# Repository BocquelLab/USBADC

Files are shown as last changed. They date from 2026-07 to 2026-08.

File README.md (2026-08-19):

# USBADC
Le USBADC est un petit PCB qui implémente plusieurs fonctionnalités:
+ Lecture de la tension de sortie du power meter
+ Lecture de la température ambiante
+ Communication USB pour interfacer avec un ordinateur
+ Génération de 28 volts 1 ampère à partir de 12 volts 3 Ampères pour l'amplificateur RF
+ Génération de 5 volts pour le power meter
+ Contrôlle de la vitesse du ventilateur pour évacuer la chaleur
+ 6 sorties open-drain pour pouvoir controller des appareils nécessitant de la puissance (`PB1`, `PB3`, `PB4`, `PB5`, `PB6`, `PB7`)
+ 6 sorties digitales 3.3 volts pour du contrôlle ne nécessitant pas de puissance (`PA3`, `PA4`, `PA5`, `PA6`, `PA7`, `PA8`)
+ LED de statut du PCB, `D2` clignote lorsque le micro-contrôlleur n'a pas d'erreurs, et 4 autres LEDs indiquent si les générateurs de tensions fonctionnent (3.3V, 5V, 12V, 28V)

## Hardware
KiCad 10.0 a été utilisé pour la conception du schématique et du PCB.

### Composantes
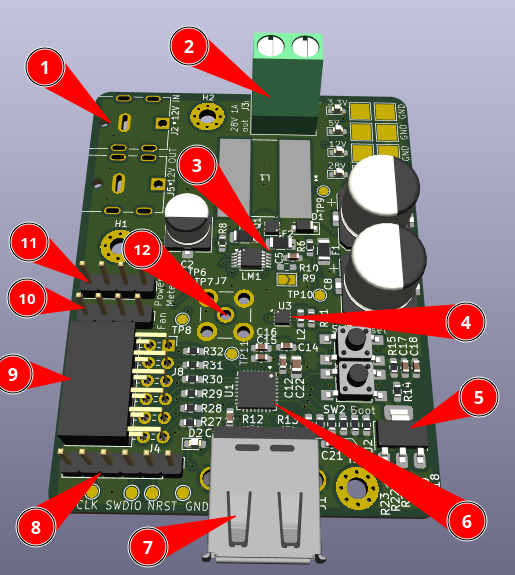
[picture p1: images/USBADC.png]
USBADC

1. Entré 12V 3A
2. Sortie 28V 1A
3. Boost 12V -> 28V
4. Buck 12V -> 5V
5. Régulateur 5V -> 3.3V
6. Microcontrôlleur STM32U073K8U6
7. Connecteur USB A femelle
8. Connecteur SWD (Single Wire Debug)
9. Sorties open-drain et low power
10. Sortie PWM pour fan
11. Sortie pour alimentation du powermeter et entrée de la température
12. Entrée pour lecture de la puissance RF

### Programmation
Pour envoyer un programme sur le micro-contrôlleur, il y a le port USB ainsi qu'un port SWD près du connecteur USB (header 6 pins).
Pour le flasher par USB, il faut utiliser le périphérique DFU (Download Firmware Upgrade) qu'expose le bootloader to STM32. Par contre, je ne sais pas pourquoi, je n'ai pas été capable de le faire fonctionner plus qu'une seule fois.

Pour le flasher par SWD, il faut un STlink. J'ai utilisé un [STlink-V3MINIE](https://www.st.com/en/development-tools/stlink-v3minie.html) auquel j'avais accès, il serait peut-être pertinent de s'en acheter un. J'ai aussi utilisé [stlink-tools](https://github.com/stlink-org/stlink) pour envoyer le programme. Il faut brancher:

| stlink | PCB |
|:---:|:-----:|
| VCC | VDD1  |
| CLK | SWCLK |
| GND | GND |
| TMS | SWDIO |
| RST | NRST  |

Le pinout du PCB est visible sur KiCad, l'ordre est VCC, SWCLK, GND, SWDIO, NRST, no-connect en partant de la pin extérieure.

### USB
La communication USB est faites avec un `STM32U073K8U6`, un micro-contrôlleur peu coûteux. C'est le moins cher qui a toutes les fonctionnalitées voulues, l'horloge pour le USB est générée à l'interne du chip.

### Génération 28V et 5V
Les bucks et boosts ont été générées avec l'outil [WEBENCH](https://webench.ti.com/power-designer/switching-regulator?powerSupply=0) de Texas Instrument pour être sûr que les circuits fonctionnent, jusqu'à maintenant, il n'y a eu aucuns problèmes.

### Sécurité
Pour la génération du 28V, il y a ~28 watts qui transitent dans cette partie du circuit. Il y a une fuse 4 ampères `F2` à l'entrée 12V du circuit et une fuse 1.5 ampères `F1` à la sortie 28V. De plus, il y a une diode schottky à la sortie 28V pour éviter d'envoyer des pics de tensions à l'amplificateur. Il y a aussi des condensateurs de capacitance équivalente 110µF pour lisser la tension entrante dans l'amplificateur.

Il y a des points de tests un peu partout sur le PCB pour être capable de débugger plus facilement si il arrive un problème.

### Boutons
Le PCB possède deux boutons, `BOOT0` et `Reset`.

`Reset` permet de redémarrer le microcontrôlleur, pratique pour débugger ou pour le redémarrer si il ne répond pas.

`BOOT0` permet de signaler au bootloader du microcontrôlleur que l'on désire flasher un programme pour qu'il expose la classe `DFU`. Il faut simplement tenir le bouton en appuyant sur `Reset`. Comme mentionné plus tôt, je ne comprends pas pourquoi je n'arrive pas à faire fonctionner cette option.

### Corrections à apporter sur une version future
Les connecteurs pour le ventilateur et le power meter overlap et ne peuvent donc pas être soudés directement sur le PCB.

Trouver pourquoi la programmation par DFU ne fonctionne pas et régler le problème.

Il m'est arrivé une fois que le board ne voulait pas démarrer, j'ai trouvé qu'il s'exposait comme périphérique DFU au démarage au lieu de CDC ACM et je n'étais pas capable de le faire booter plus loin que le bootloader. Je l'ai reflashé et ça a fonctionné, je n'ai pas revu ça depuis.

Mettre un connecteur USB mâle à la place d'un connecteur USB femelle car les connecteurs femelles sont réservés aux hôtes USB et les mâles aux périphériques.

Monitorer la tension du 28V avec le STM32 pour pouvoir voir son statut par USB au lieu de devoir regarder la LED. Sur la version actuelle, il est possible de mettre un diviseur de tension sur le pad 28V et rentrer ça dans la pin A3.

## Firmware
La grande majorité du code dans `firmware/` a été générée avec `STM32CubeMX`, un outil pour initialiser des projets pour des STM32, ils s'occupent d'initialiser toutes les périphériques, vérifier que la configuration de clocks choisie est correcte, etc.

Les paramètres pour CubeMX sont dans le fichier `firmware/USBADC.ioc`.

Le coeur de la logique a été implémentée dans `firmware/USBX/App/` en C.

### Compilation
Pour compiler le programme, il suffit d'écrire `make` si la toolchain de développement `arm` est installée. Je développais sur un ordinateur Linux et je roulais souvant 
```
make -j4; st-flash erase; st-flash write build/USBADC.bin 0x08000000
```
pour compiler et puis envoyer le programme sur le microcontrôlleur. Je ne suis pas certain que les `Makefile` sont supportés dans `STM32CubeIDE` (IDE de développement pour un STM32 installée sur l'ordinateur du laboratoire).

J'ai utilisé la "Arm GNU Toolchain 15.2.Rel1 (Build arm-15.86)) 15.2.1 20251203". Tout fonctionne avec celle là, il n'y a surement pas de soucis à prendre une autre version.

### Débuggage
Pour débugger, `STM32CubeIDE` et `stlink-tools` permettent d'ouvrir une session `gdb` et d'explorer la mémoire du microcontrolleur. Avec `stlink-tools`, je roulais dans un terminal `st-util` et dans l'autre `gdb build/USBADC.elf`, puis dans la session gdb `target remote localhost:4242`.

### Connection USB
Le périphérique USB crée expose une classe USB CDC ACM, (Character Device Class, Abstract Control Modem). Cette classe permet d'envoyer une série d'octet à l'appareil ainsi que d'en recevoir une. Lorsque branchée dans un ordinateur, le PCB devrait apparaître comme `/dev/ttyUSB*` sur Linux et `COM*` sur Windows. La LED devrait aussi clignotée si le microcontrôlleur est alimentée correctement et qu'il n'y a pas d'erreurs.

### Protocole de communication
La communication se produit par paquets entre le serveur (l'ordinateur) et le client (l'USBADC).
Un packet est une liste d'octets qui représente une commande ou une réponse. Le préfixe `0x` dénote de l'hexadécimale.

| Bytes | Name | Type | Description |
|---|---|---|---|
| `0-3` | Magic | `u8[4]` | `0xAA` `0x55` `0xAA` `0x55` |
| `4-5` | ID | `u16` | Request/response identifier. |
| `6` | Type | `u8` | Message type. |
| `7` | Data Length | `u8` | Bytes following this field. |
| `8..7+N` | Data | `u8[]` | Type-specific payload. |
| `8+N..11+N` | CRC | `u32` | Packet checksum using CRC32. |

Le champs `Magic` permet d'identifier le début d'un paquet. `0xAA55AA55` a été choisi car c'est une séquence qui a peu de chance d'arriver avec du bruit ou dans des données, aussi, en binaire, les bits de 0xAA et 0x55 alternent et ça permet de reconnaitre à l'oeil le début de la séquence.

Le champs `ID` permet à l'USBADC de spécifier à quel paquet il répond en spécifiant l'ID du message qu'il a reçu dans sa réponse. Cela permet de répondre aux paquets dans un ordre différent de celui dans lequel ils ont été reçues si besoin.

Le champs `Type` est le type du message (ping, read_adc, write_pin, reboot, ...) et permet de spécifier comment interpréter les données,

Le champs `Data Length` est la longeur du champs `Data` en octets

Le champs `Data` est les données associées au `Type` choisi.

Le champs `CRC` (Cyclical Redundancy Checksum) sert à vérifier l'intégrité des données reçues. Lors de la réception d'un paquet, on calcule le checksum de tous les octets précédents. Si le checksum est identique à celui reçue, on peut être confiant qu'il n'y a pas eu d'erreur de transmission.

Le protocole est ses fonctions de sérialisation/désérialisation sont spécifiées dans `firmware/USBX/App/protocol.h` et `firmware/USBX/App/protocol.c`.
Les structures qui représentent les données transmises ont l'attribut `__attribute__((packed))` pour éviter les champs de "padding". Cet attribute garanti qu'il n'y en aura pas.

Sur le message `REQUEST_PING`, le client répond avec le message `RESPONSE_PONG` avec les mêmes données. Cela permet de s'assurer que le client fonctionne correctement.

Sur le message `REQUEST_READ_ADC`, le client répond avec `RESPONSE_READ_ADC` la tension lue sur le channel correspondant.

Sur le mesasge `REQUEST_WRITE_PIN`, le client répond avec `RESPONSE_STATUS` et sort l'état demandée sur la pin demandée.

Sur le mesasge `REQUEST_REBOOT`, le client répond avec `RESPONSE_STATUS` et redémarre (la communication sera coupée).

Sur le message `REQUEST_VERSION`, le client répond avec la version du protocole qu'il utilise. Cela permet de s'assurer que le client et le serveur sont sur la même version et que toutes les fonctionnalitées sont fonctionelles et supportées des deux côtés.

Sur tous les messages, le client peut répondre avec `RESPONSE_STATUS` et spécifier la raison (`enum USBADC_PROTOCOL_RESPONS_STATUS_REASONS`).

### Fichiers (`firmware/USBX/App/`)
+ `app_usbx_device.c`: Point d'entrée `ThreadX` qui initialise les tâches et le périphérique USB et les files.
+ `ux_device_cdc_acm.c`: Définitions de toutes les tâches concurrentes qui roulent, dont l'écriture et la lecture sur le canal USB, la lecture de l'ADC et le contrôle de la vitesse du ventilateur.
+ `byte_vector.c`: Définition des fonctions pour manipuler une liste d'octets qui ne peut pas être agrandie.
+ `protocol.c`: Définition des fonctions pour sérialiser/désérialiser les packets envoyées/reçues

## Software
Python 3.11 a été utilisé.

Dans `software/USBADC.py`, il y a la classe `USBADC` qui permet de communiquer avec le périphérique. Il est nécessaire d'installer `pyserial` pour être capable de communiquer.

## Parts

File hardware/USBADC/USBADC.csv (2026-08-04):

Reference | Qty | Value | DNP | Exclude from BOM | Exclude from Board | Footprint | Datasheet
C1 | 1 | 10p |  |  |  | Capacitor_SMD:C_0603_1608Metric_Pad1.08x0.95mm_HandSolder
C2 | 1 | 100u |  |  |  | Capacitor_SMD:CP_Elec_6.3x5.8 | https://www.digikey.ca/en/products/detail/nichicon/UUD1C101MCL1GS/590003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
C3 | 1 | 1n |  |  |  | Capacitor_SMD:C_0603_1608Metric_Pad1.08x0.95mm_HandSolder
C4,C19,C20,C21 | 4 | 470p |  |  |  | Capacitor_SMD:C_0603_1608Metric_Pad1.08x0.95mm_HandSolder
C5 | 1 | 1.2u |  |  |  | Capacitor_SMD:C_0603_1608Metric_Pad1.08x0.95mm_HandSolder
C6,C8 | 2 | 220u |  |  |  | Capacitor_SMD:CP_Elec_10x10 | UUD1H221MNL1GS
C7,C12,C13,C17,C18 | 5 | 100n |  |  |  | Capacitor_SMD:C_0603_1608Metric_Pad1.08x0.95mm_HandSolder
C10,C11 | 2 | 10u |  |  |  | Capacitor_SMD:C_0805_2012Metric_Pad1.18x1.45mm_HandSolder | CL21A106KOQNNNE,https://www.digikey.ca/en/products/detail/samsung-electro-mechanics/CL21A106KOQNNNE/3886754
C14 | 1 | 4.7u |  |  |  | Capacitor_SMD:C_0603_1608Metric_Pad1.08x0.95mm_HandSolder
C15 | 1 | 10n |  |  |  | Capacitor_SMD:C_0603_1608Metric_Pad1.08x0.95mm_HandSolder
C16 | 1 | 1u |  |  |  | Capacitor_SMD:C_0603_1608Metric_Pad1.08x0.95mm_HandSolder
C22 | 1 | 10u |  |  |  | Capacitor_SMD:C_0603_1608Metric_Pad1.08x0.95mm_HandSolder
D1 | 1 | 550mV 2A |  |  |  | Diode_SMD:D_SOD-123F | https://www.digikey.ca/en/products/detail/onsemi/SS24FL/5305066
D2,D3,D4,D5,D6 | 5 | LED |  |  |  | LED_SMD:LED_0603_1608Metric_Pad1.05x0.95mm_HandSolder | https://www.digikey.ca/en/products/detail/liteon/LTST-C190KGKT/386815
D7 | 1 | 28V |  |  |  | Diode_SMD:D_SMA_Handsoldering | https://www.digikey.ca/en/products/detail/littelfuse-inc/SMAJ28CA/762293
F1,F2 | 2 | Fuse |  |  |  | Fuse:Fuse_1206_3216Metric_Pad1.42x1.75mm_HandSolder | https://www.digikey.ca/en/products/detail/bel-fuse-inc/0685T1500-01/4968265,https://www.digikey.ca/en/products/detail/bel-fuse-inc/0685T4000-01/4968270
J1 | 1 | USB_A |  |  |  | Connector_USB:USB_A_Molex_67643_Horizontal
J2,J5,J6 | 3 | JACK-C-PC-10A-RA_R |  |  |  | Library:GLOBTECK_JACK-C-PC-10A-RA_R_ | https://www.digikey.com/en/products/detail/globtek-inc/JACK-C-PC-10A-RA-R/8597889
J4 | 1 | Conn_01x06 |  |  |  | Connector_PinHeader_2.54mm:PinHeader_1x06_P2.54mm_Vertical
J7 | 1 | RFPC-SMA28-F |  |  |  | Library:GRADCONN_RFPC-SMA28-F
J8 | 1 | Conn_02x06_Odd_Even |  |  |  | Connector_PinSocket_2.54mm:PinSocket_2x06_P2.54mm_Horizontal
J9,J10 | 2 | Conn_01x04_Pin |  |  |  | Connector_PinHeader_2.54mm:PinHeader_1x04_P2.54mm_Vertical | https://www.digikey.ca/en/products/detail/molex/0470531000/2421261?s=N4IgTCBcDaIAwBYDscCsBmAjHHIC6AvkA
L1 | 1 | SDR1307-180ML |  |  |  | Library:IND_BOURNS_SDR1307 | SDR1307-180ML
L2 | 1 | 2.2u |  |  |  | Inductor_SMD:L_0603_1608Metric_Pad1.05x0.95mm_HandSolder | MLZ1608N2R2LT000
LM1 | 1 |  |  |  |  | Package_SO:TSSOP-10_3x3mm_P0.5mm | https://www.digikey.ca/en/products/detail/texas-instruments/LM3481MMX-NOPB/1840677
Q1 | 1 | CSD19538Q2 |  |  |  | Package_SON:Texas_DQK | https://www.ti.com/lit/ds/symlink/csd19538q2.pdf
Q2,Q3,Q4,Q5,Q6,Q7 | 6 | Q_NMOS_GSD |  |  |  | Package_TO_SOT_SMD:SOT-523 | https://www.digikey.ca/en/products/detail/diodes-incorporated/DMN62D0UT-7/5721509
R1 | 1 | 20m |  |  |  | Resistor_SMD:R_1206_3216Metric_Pad1.30x1.75mm_HandSolder | https://www.digikey.ca/en/products/detail/stackpole-electronics-inc/CSR1206FK20L0/1646092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
R2 | 1 | 44.2k |  |  |  | Resistor_SMD:R_0603_1608Metric_Pad0.98x0.95mm_HandSolder
R3 | 1 | 6.34 |  |  |  | Resistor_SMD:R_0603_1608Metric_Pad0.98x0.95mm_HandSolder
R4 | 1 | 73.2k |  |  |  | Resistor_SMD:R_0603_1608Metric_Pad0.98x0.95mm_HandSolder
R5 | 1 | 976 |  |  |  | Resistor_SMD:R_0603_1608Metric_Pad0.98x0.95mm_HandSolder
R6 | 1 | 21k |  |  |  | Resistor_SMD:R_0603_1608Metric_Pad0.98x0.95mm_HandSolder
R7 | 1 | 34k |  |  |  | Resistor_SMD:R_0603_1608Metric_Pad0.98x0.95mm_HandSolder
R8 | 1 | 100 |  |  |  | Resistor_SMD:R_0603_1608Metric_Pad0.98x0.95mm_HandSolder
R9 | 1 | 0 |  |  |  | Jumper:SolderJumper-2_P1.3mm_Open_TrianglePad1.0x1.5mm
R10 | 1 | 1 | DNP |  |  | Resistor_SMD:R_0603_1608Metric_Pad0.98x0.95mm_HandSolder
R11 | 1 | 100k |  |  |  | Resistor_SMD:R_0603_1608Metric_Pad0.98x0.95mm_HandSolder
R12 | 1 | 15k |  |  |  | Resistor_SMD:R_0603_1608Metric_Pad0.98x0.95mm_HandSolder
R13,R14,R15,R18,R19,R20,R21,R22,R23,R27,R28,R29,R30,R31,R32 | 15 | 10k |  |  |  | Resistor_SMD:R_0603_1608Metric_Pad0.98x0.95mm_HandSolder
R16,R17 | 2 | 62 |  |  |  | Resistor_SMD:R_0603_1608Metric_Pad0.98x0.95mm_HandSolder
R24 | 1 | 150 |  |  |  | Resistor_SMD:R_0603_1608Metric_Pad0.98x0.95mm_HandSolder
R25 | 1 | 510 |  |  |  | Resistor_SMD:R_0603_1608Metric_Pad0.98x0.95mm_HandSolder
R26 | 1 | 1300 |  |  |  | Resistor_SMD:R_0603_1608Metric_Pad0.98x0.95mm_HandSolder
SW2,SW3 | 2 | SW_Push |  |  |  | Button_Switch_SMD:SW_SPST_TL3305B | https://www.digikey.ca/en/products/detail/e-switch/TL3305BF100QG/25324184
TP5,TP6,TP7,TP8,TP9,TP10,TP11,TP12,TP13,TP14 | 10 | TestPoint |  |  |  | TestPoint:TestPoint_Pad_D1.5mm
TP17,TP18,TP20,TP21,TP23,TP24,TP25,TP29 | 8 | TestPoint |  |  |  | TestPoint:TestPoint_Pad_3.0x3.0mm
U1 | 1 | STM32U073K8Ux |  |  |  | Package_DFN_QFN:QFN-32-1EP_5x5mm_P0.5mm_EP3.45x3.45mm | https://www.st.com/resource/en/datasheet/stm32u073k8.pdf
U2 | 1 | AMS1117-3.3 |  |  |  | Package_TO_SOT_SMD:SOT-223-3_TabPin2 | http://www.advanced-monolithic.com/pdf/ds1117.pdf
U3 | 1 | TPS62173DSG |  |  |  | Package_SON:WSON-8-1EP_2x2mm_P0.5mm_EP0.9x1.6mm_ThermalVias | http://www.ti.com/lit/ds/symlink/tps62170.pdf

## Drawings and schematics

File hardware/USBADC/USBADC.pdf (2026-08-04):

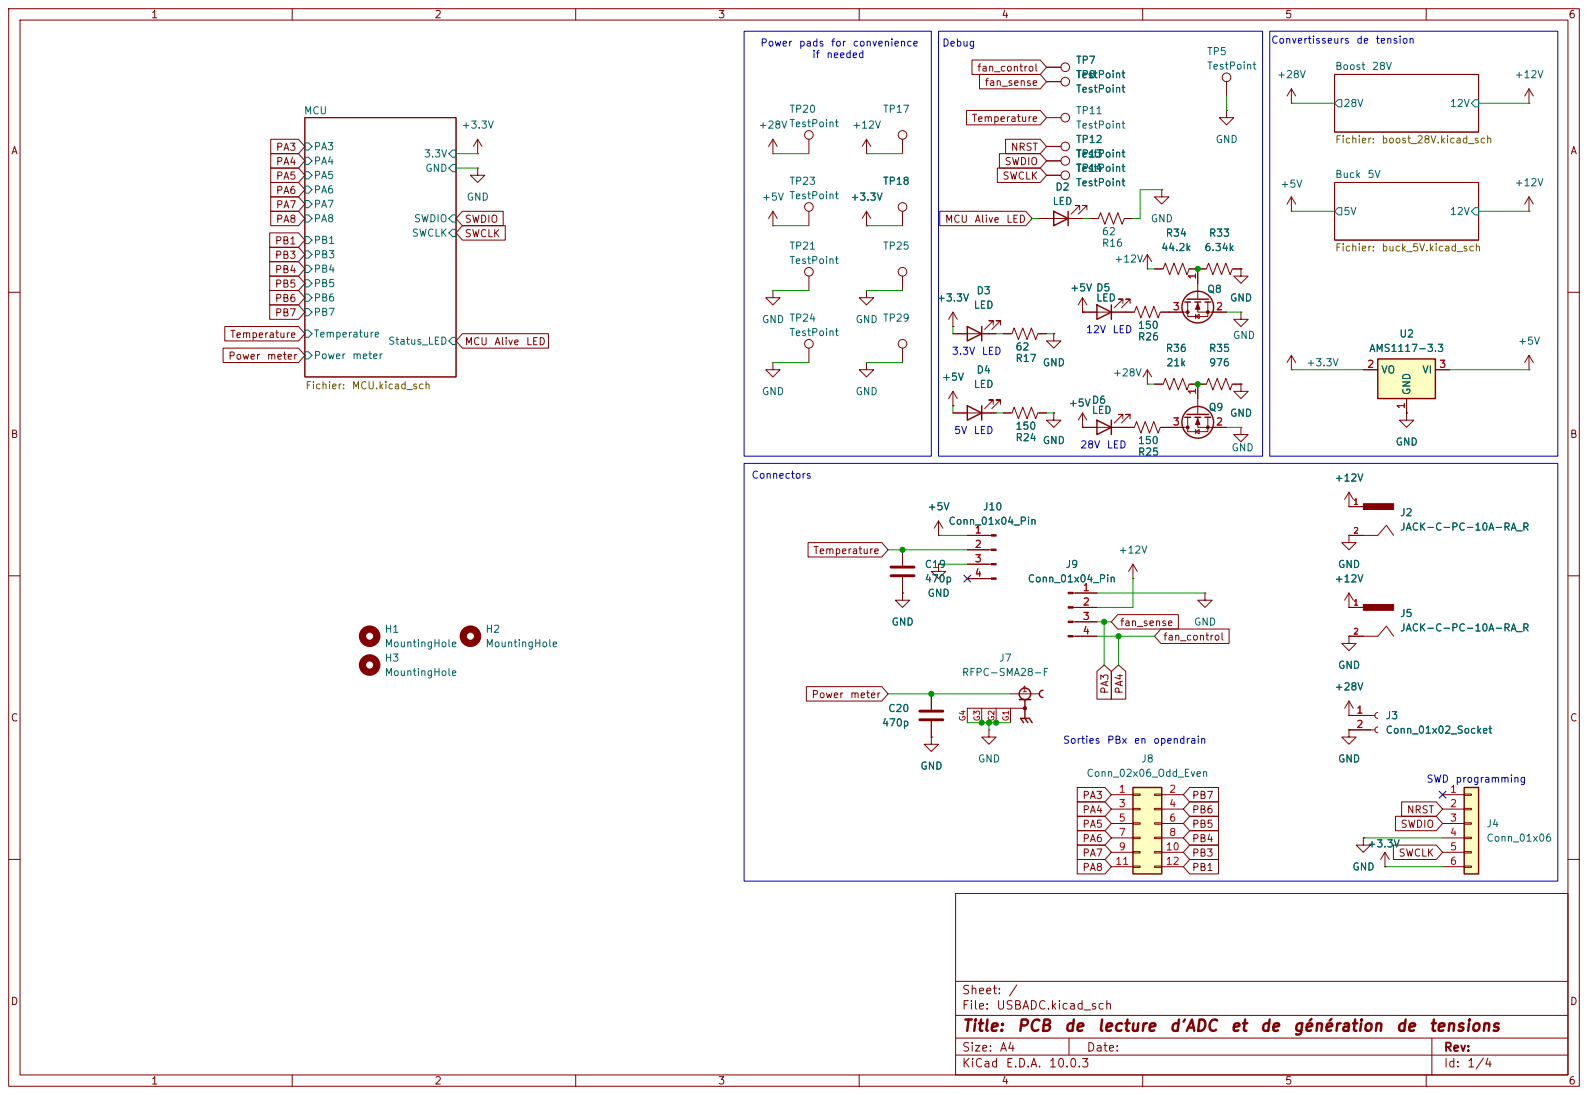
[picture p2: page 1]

Power pads for convenience

NRST SWCLK MCU Alive LED

SWD programming Sorties PBx en opendrain 3.3V LED

Sheet: /
File: USBADC.kicad_sch
Title: PCB de lecture d'ADC et de génération de tensions

Size: A4 | Rev:
KiCad E.D.A. 10.0.3 | Id: 1/4

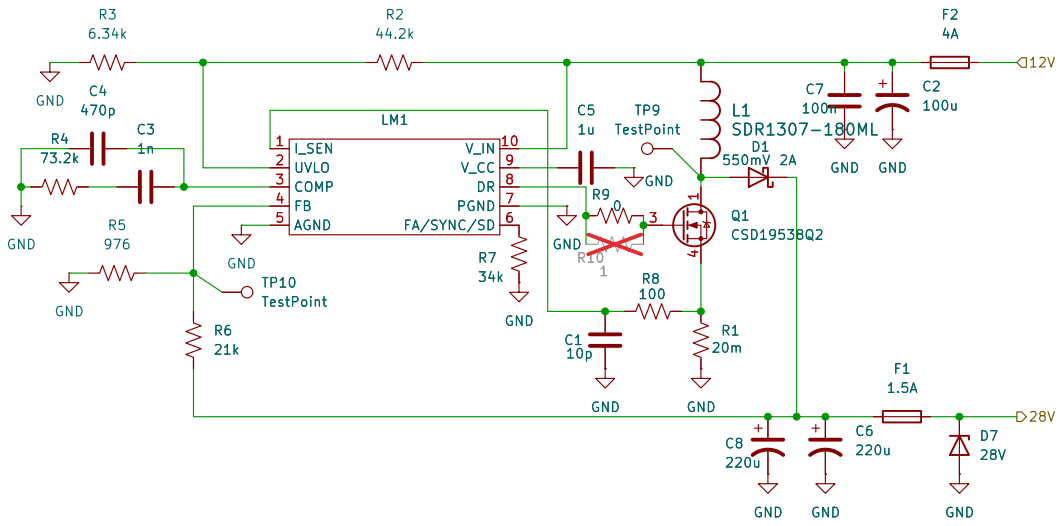
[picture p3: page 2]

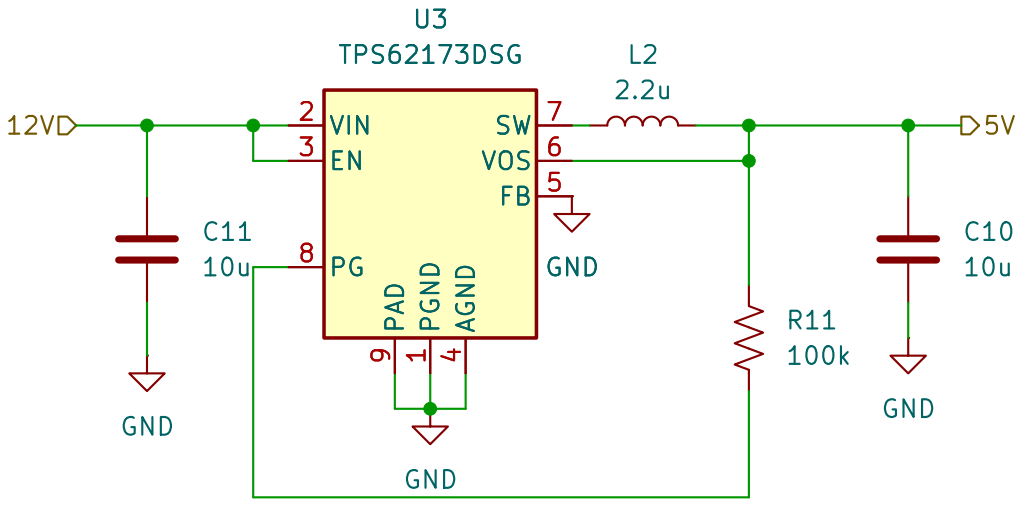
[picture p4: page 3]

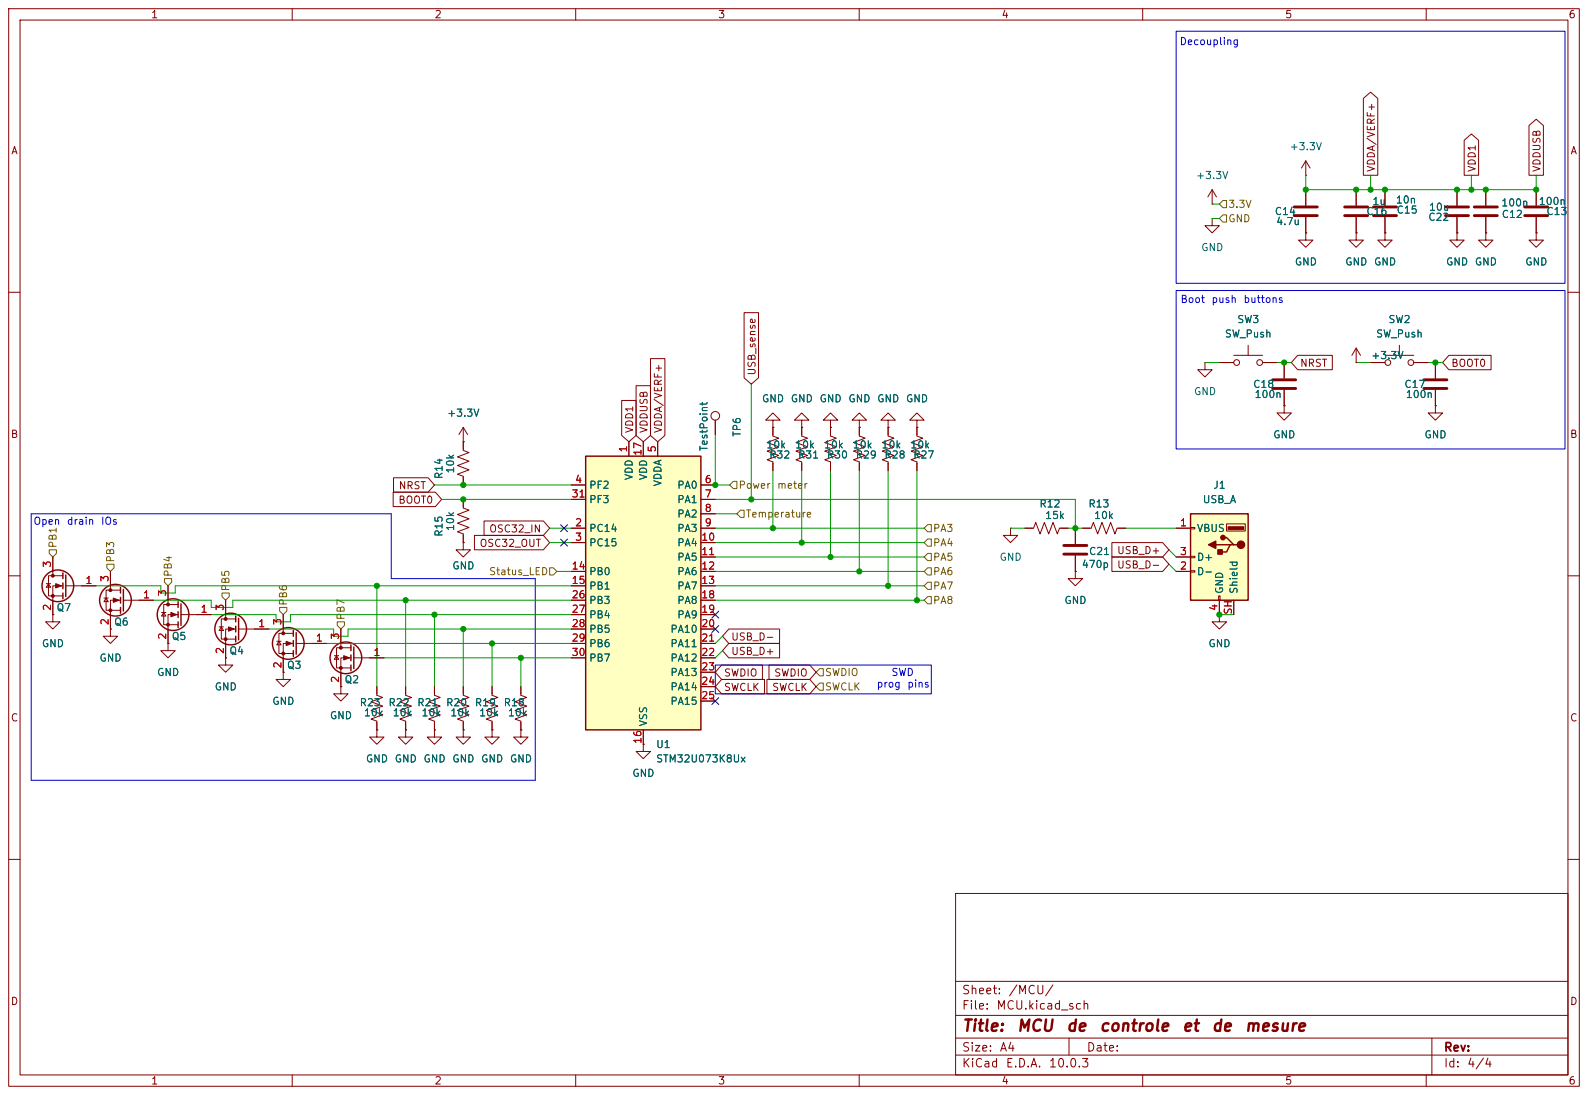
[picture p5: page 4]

SWCLK USB_D-USB_sense VDD1 VDDUSB VDDA/VERF+

1 PC14 2 PC15 3 PF2 4 VDDA 5 PA0 6 PA1 7 PA2 8 PA3 9 PA4 10 PA5 11 PA6 12 PA7 13 PB0 14 PB1 15 VSS 16 VDD 17 PA8 18 PA9 19 PA10 20 PA11 21 PA12 22 PA13 23 PA14 24 PA15 25 PB3 26 PB4 27 PB5 28 PB6 29 PB7 30 PF3 31 GND TP6 TestPoint C22

File: MCU.kicad_sch
Title: MCU de controle et de mesure

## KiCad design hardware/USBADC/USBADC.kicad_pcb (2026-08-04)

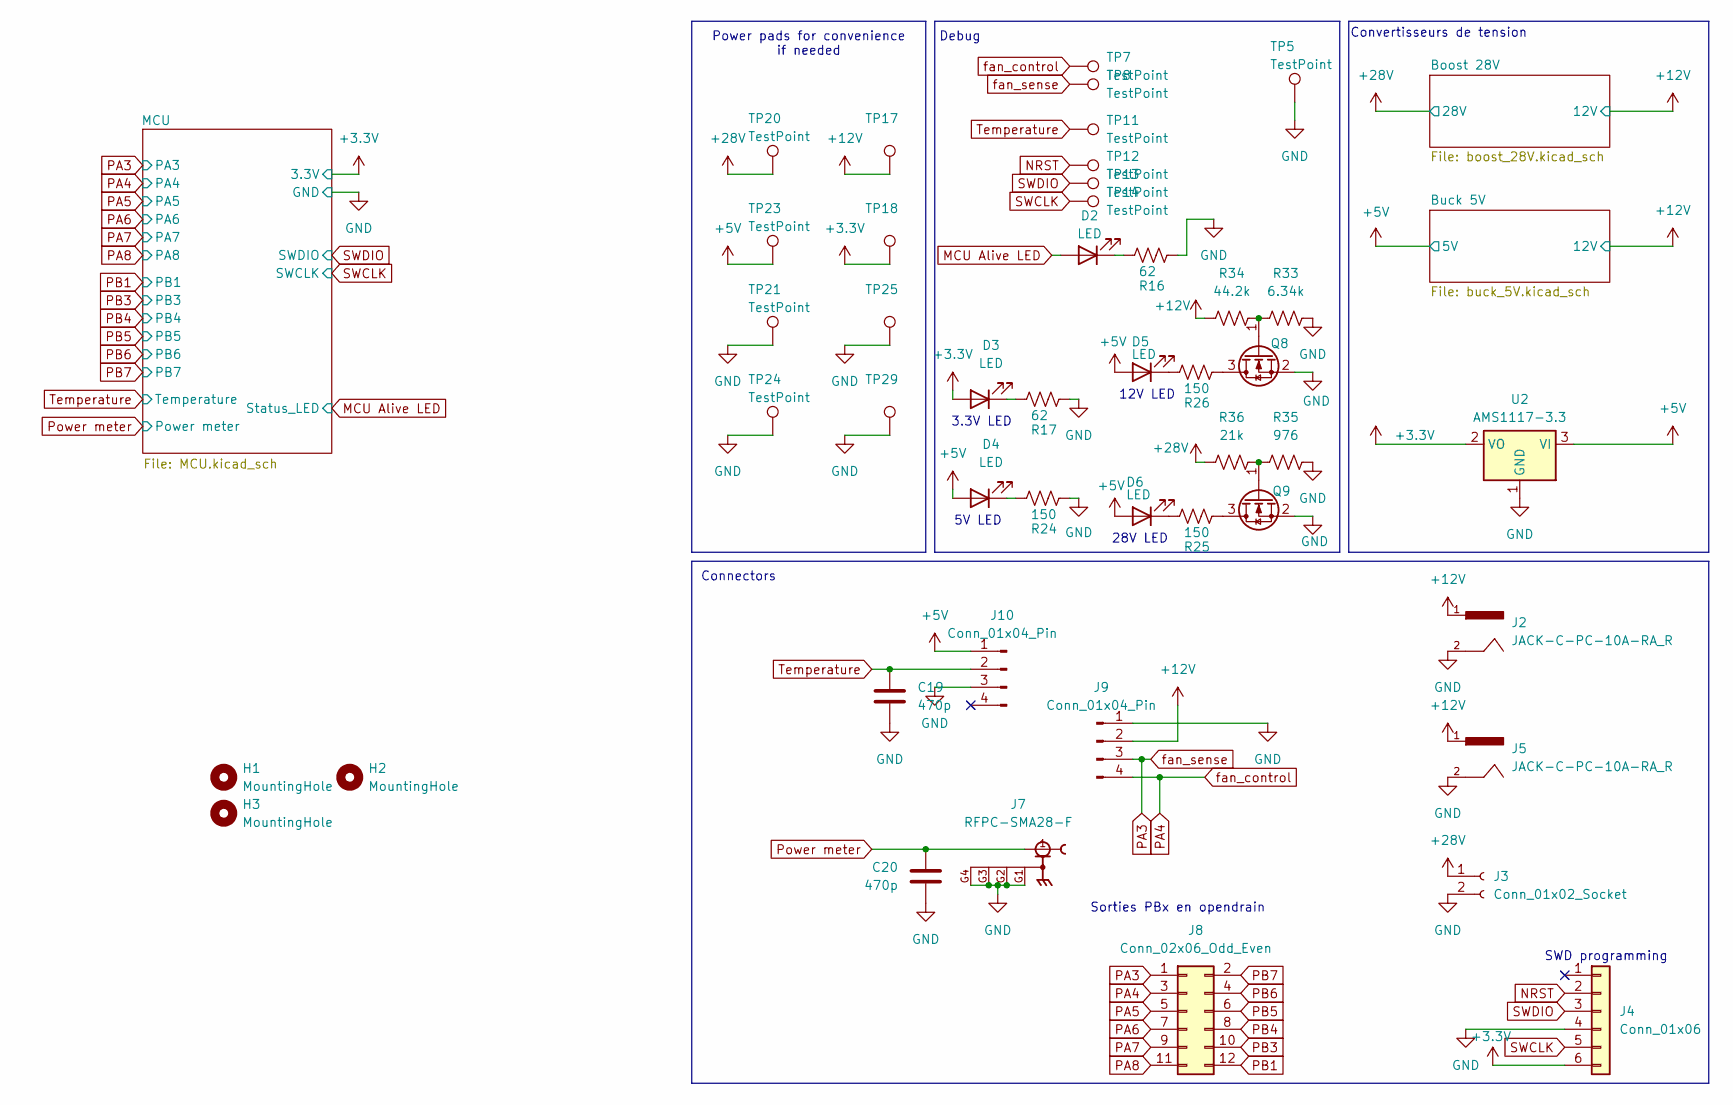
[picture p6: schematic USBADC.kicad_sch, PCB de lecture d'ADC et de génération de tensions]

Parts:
C19, C20: 470p; C_0603_1608Metric_Pad1.08x0.95mm_HandSolder
D2, D3, D4, D5, D6: LED; LED_0603_1608Metric_Pad1.05x0.95mm_HandSolder
H1, H2, H3: MountingHole; MountingHole_2.7mm_Pad_Via
J2, J5: JACK-C-PC-10A-RA_R; GLOBTECK_JACK-C-PC-10A-RA_R_; PARTREV A
J3: Conn_01x02_Socket; TerminalBlock_Phoenix_MKDS-1,5-2_1x02_P5.00mm_Horizontal
J4: Conn_01x06; PinHeader_1x06_P2.54mm_Vertical
J7: RFPC-SMA28-F; GRADCONN_RFPC-SMA28-F; PARTREV 1.0
J8: Conn_02x06_Odd_Even; PinSocket_2x06_P2.54mm_Horizontal
J9, J10: Conn_01x04_Pin; PinHeader_1x04_P2.54mm_Vertical
Q8, Q9: Q_NMOS_GSD; SOT-523
R16, R17: 62; R_0603_1608Metric_Pad0.98x0.95mm_HandSolder
R24, R25, R26: 150; R_0603_1608Metric_Pad0.98x0.95mm_HandSolder
R33: 6.34k; R_0603_1608Metric_Pad0.98x0.95mm_HandSolder
R34: 44.2k; R_0603_1608Metric_Pad0.98x0.95mm_HandSolder
R35: 976; R_0603_1608Metric_Pad0.98x0.95mm_HandSolder
R36: 21k; R_0603_1608Metric_Pad0.98x0.95mm_HandSolder
TP5, TP7, TP8, TP11, TP12, TP13, TP14: TestPoint; TestPoint_Pad_D1.5mm
TP17, TP18, TP20, TP21, TP23, TP24, TP25, TP29: TestPoint; TestPoint_Pad_3.0x3.0mm
U2: AMS1117-3.3; SOT-223-3_TabPin2

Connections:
+5V: D4.2 (A), D5.2 (A), D6.2 (A), J10.1, TP23.1 (1_1), U2.3 (VI); also elsewhere on the board
+12V: J2.1, J5.1, J9.2, R34.1, TP17.1 (1_1); also elsewhere on the board
+28V: J3.1, R36.1, TP20.1 (1_1); also elsewhere on the board
GND: C19.1, C20.1, J2.2, J3.2, J4.4, J5.2, J7.G1, J7.G2, J7.G3, J7.G4, J9.1, J10.3, Q8.2 (S), Q9.2 (S), R16.1, R17.1, R24.1, R33.1, R35.1, TP5.1 (1_1), TP21.1 (1_1), TP24.1 (1_1), TP25.1 (1_1), TP29.1 (1_1), U2.1 (GND); also elsewhere on the board
MCU Alive LED: D2.2 (A); also elsewhere on the board
NRST: J4.2, TP12.1 (1_1); also elsewhere on the board
unnamed: D2.1 (K), R16.2
unnamed: D3.1 (K), R17.2
unnamed: D4.1 (K), R24.2
unnamed: D5.1 (K), R26.2
unnamed: D6.1 (K), R25.2
unnamed: Q8.3 (D), R26.1
unnamed: Q8.1 (G), R33.2, R34.2
unnamed: Q9.3 (D), R25.1
unnamed: Q9.1 (G), R35.2, R36.2
PA3: J8.1, J9.3, TP8.1 (1_1); also elsewhere on the board
PA4: J8.3, J9.4, TP7.1 (1_1); also elsewhere on the board
PA5: J8.5; also elsewhere on the board
PA6: J8.7; also elsewhere on the board
PA7: J8.9; also elsewhere on the board
PA8: J8.11; also elsewhere on the board
PB1: J8.12; also elsewhere on the board
PB3: J8.10; also elsewhere on the board
PB4: J8.8; also elsewhere on the board
PB5: J8.6; also elsewhere on the board
PB6: J8.4; also elsewhere on the board
PB7: J8.2; also elsewhere on the board
Power meter: C20.2, J7.1; also elsewhere on the board
SWCLK: J4.5, TP14.1 (1_1); also elsewhere on the board
SWDIO: J4.3, TP13.1 (1_1); also elsewhere on the board
Temperature: C19.2, J10.2, TP11.1 (1_1); also elsewhere on the board
VDD1: D3.2 (A), J4.6, TP18.1 (1_1), U2.2 (VO); also elsewhere on the board

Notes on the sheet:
SWD programming
Convertisseurs de tension
28V LED
Connectors
Power pads for convenience if needed
12V LED
Debug
Sorties PBx en opendrain
3.3V LED
5V LED

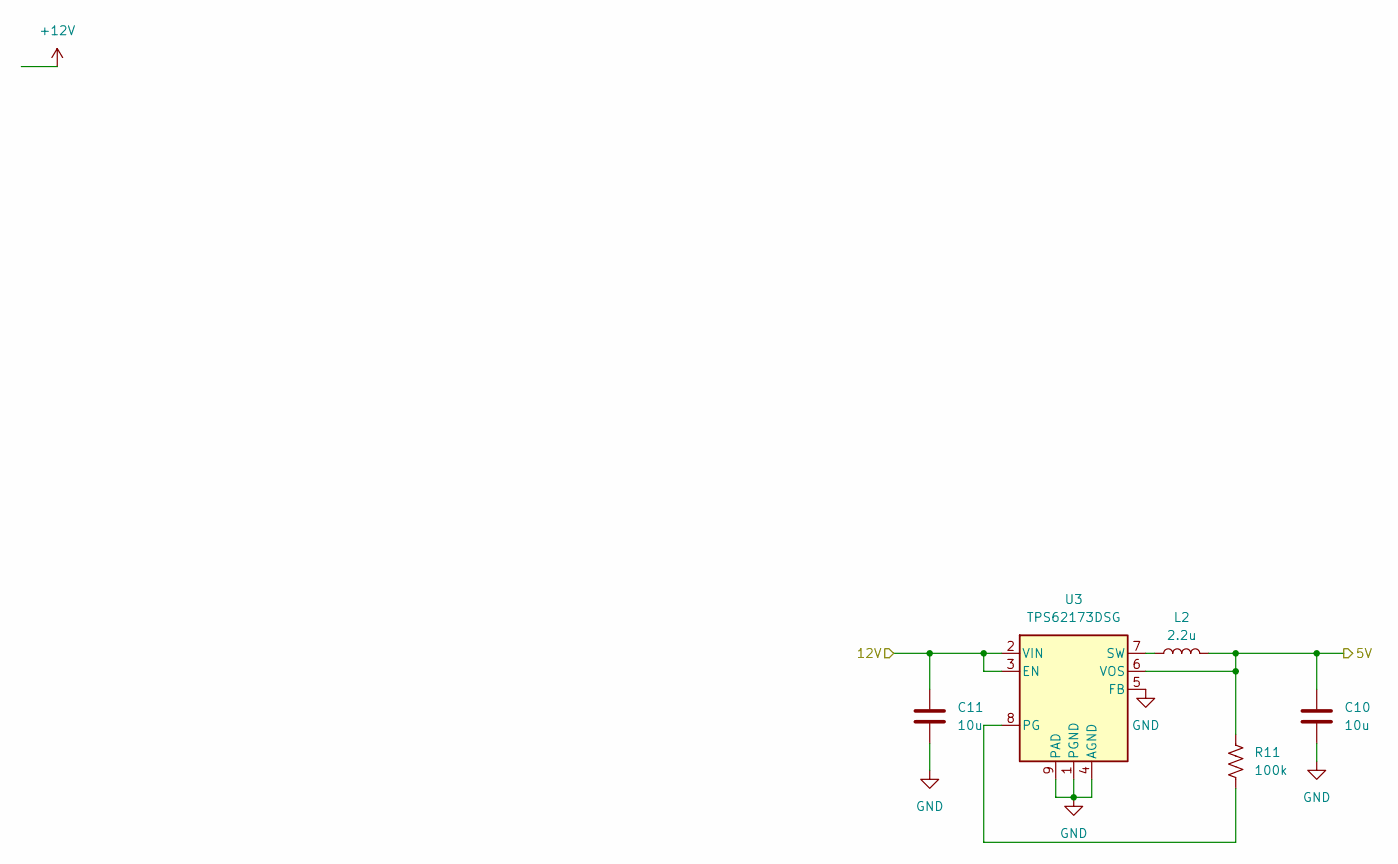
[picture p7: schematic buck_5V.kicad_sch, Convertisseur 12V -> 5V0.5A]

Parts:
C10, C11: 10u; C_0805_2012Metric_Pad1.18x1.45mm_HandSolder
L2: 2.2u; L_0603_1608Metric_Pad1.05x0.95mm_HandSolder
R11: 100k; R_0603_1608Metric_Pad0.98x0.95mm_HandSolder
U3: TPS62173DSG; WSON-8-1EP_2x2mm_P0.5mm_EP0.9x1.6mm_ThermalVias

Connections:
+5V: C10.1, L2.2, R11.1, U3.6 (VOS); also elsewhere on the board
+12V: C11.1, U3.2 (VIN), U3.3 (EN); also elsewhere on the board
GND: C10.2, C11.2, U3.1 (PGND), U3.4 (AGND), U3.5 (FB), U3.9 (PAD); also elsewhere on the board
unnamed: R11.2, U3.8 (PG)
unnamed: L2.1, U3.7 (SW)

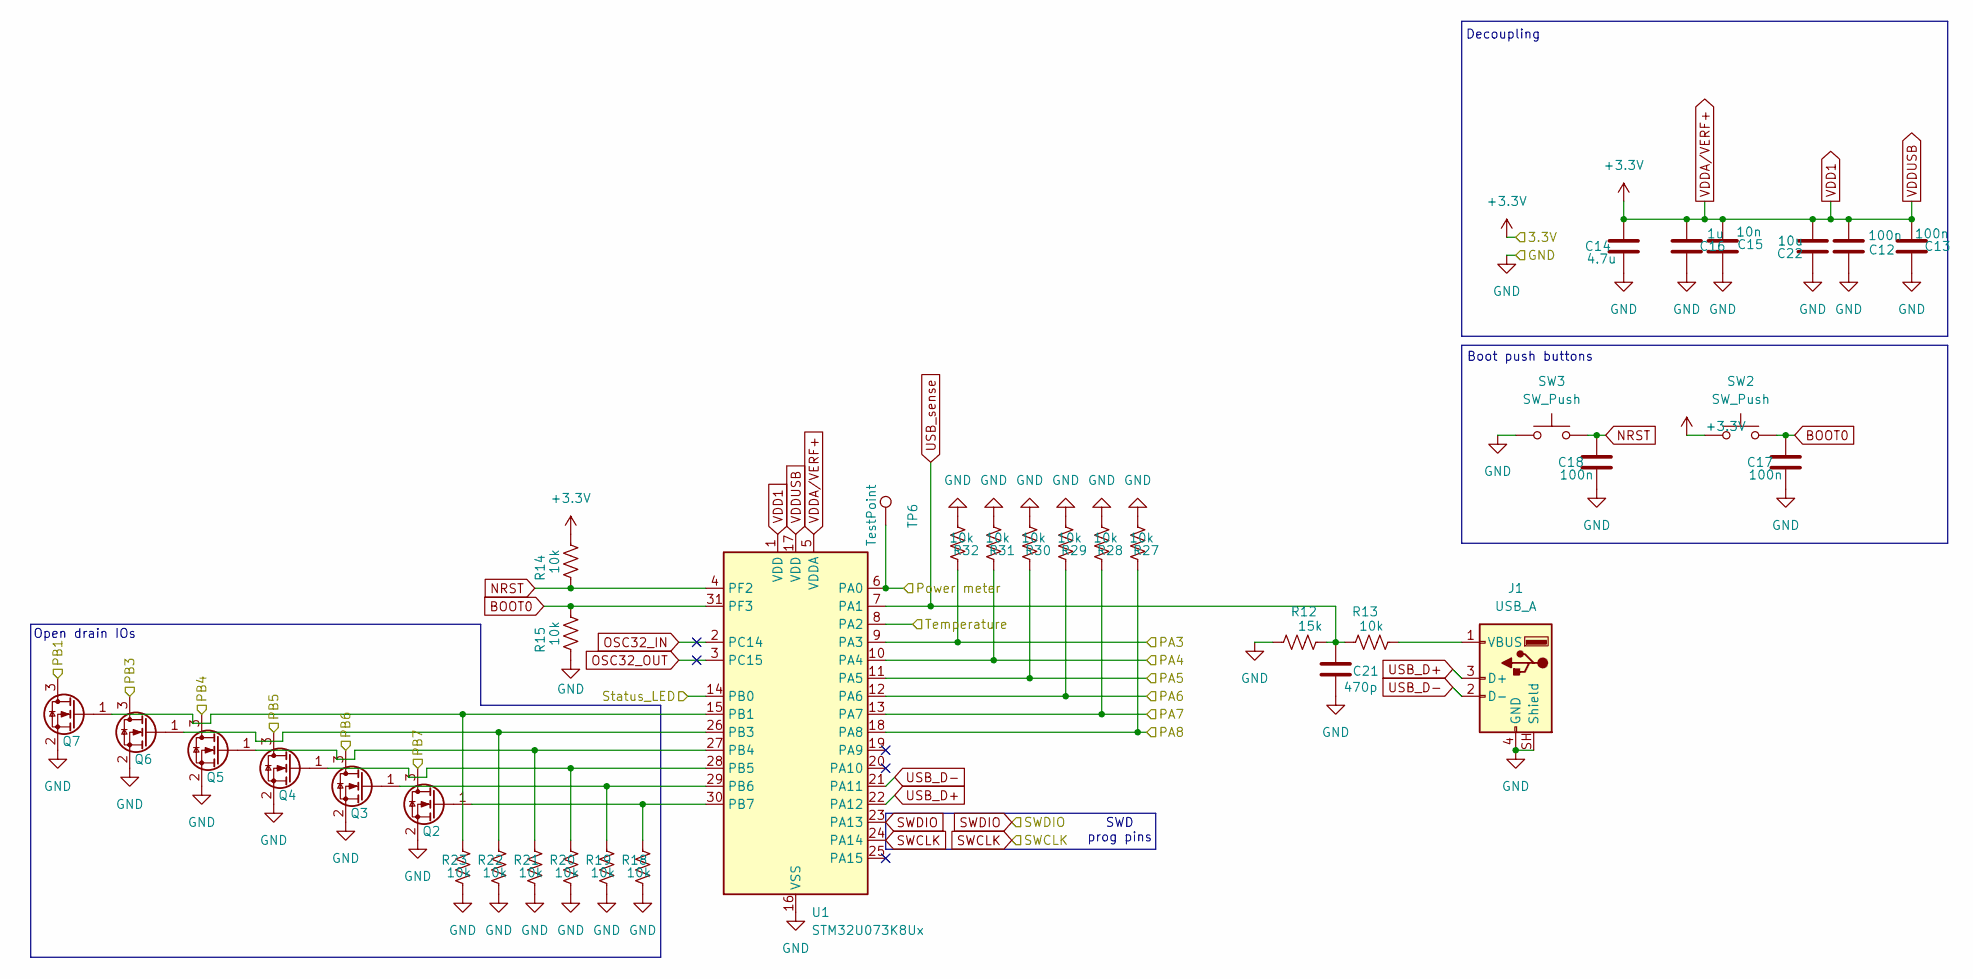
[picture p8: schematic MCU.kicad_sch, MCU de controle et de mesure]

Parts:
C12, C13, C17, C18: 100n; C_0603_1608Metric_Pad1.08x0.95mm_HandSolder
C14: 4.7u; C_0603_1608Metric_Pad1.08x0.95mm_HandSolder
C15: 10n; C_0603_1608Metric_Pad1.08x0.95mm_HandSolder
C16: 1u; C_0603_1608Metric_Pad1.08x0.95mm_HandSolder
C21: 470p; C_0603_1608Metric_Pad1.08x0.95mm_HandSolder
C22: 10u; C_0805_2012Metric_Pad1.18x1.45mm_HandSolder
J1: USB_A; USB_A_Molex_67643_Horizontal
Q2, Q3, Q4, Q5, Q6, Q7: Q_NMOS_GSD; SOT-523
R12: 15k; R_0603_1608Metric_Pad0.98x0.95mm_HandSolder
R13, R14, R15, R18, R19, R20, R21, R22, R23, R27, R28, R29, R30, R31, R32: 10k; R_0603_1608Metric_Pad0.98x0.95mm_HandSolder
SW2, SW3: SW_Push; SW_SPST_TL3305B
TP6: TestPoint; TestPoint_Pad_D1.5mm
U1: STM32U073K8Ux; QFN-32-1EP_5x5mm_P0.5mm_EP3.45x3.45mm

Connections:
BOOT0: C17.1, R15.2, SW2.2, U1.31 (PF3)
GND: C12.1, C13.1, C14.2, C15.1, C16.1, C17.2, C18.2, C21.1, C22.1, J1.4 (GND), J1.SH (Shield), Q2.2 (S), Q3.2 (S), Q4.2 (S), Q5.2 (S), Q6.2 (S), Q7.2 (S), R12.1, R15.1, R18.1, R19.1, R20.1, R21.1, R22.1, R23.1, R27.1, R28.1, R29.1, R30.1, R31.1, R32.1, SW3.1, U1.16 (VSS), U1.32 (VSS), U1.33 (VSS); also elsewhere on the board
MCU Alive LED: U1.14 (PB0); also elsewhere on the board
NRST: C18.1, R14.1, SW3.2, U1.4 (PF2); also elsewhere on the board
unnamed: J1.1 (VBUS), R13.2
unnamed: Q2.1 (G), R18.2, U1.30 (PB7)
unnamed: Q3.1 (G), R19.2, U1.29 (PB6)
unnamed: Q4.1 (G), R20.2, U1.28 (PB5)
unnamed: Q5.1 (G), R21.2, U1.27 (PB4)
unnamed: Q6.1 (G), R22.2, U1.26 (PB3)
unnamed: Q7.1 (G), R23.2, U1.15 (PB1)
OSC32_IN: U1.2 (PC14)
OSC32_OUT: U1.3 (PC15)
PA3: R32.2, U1.9 (PA3); also elsewhere on the board
PA4: R31.2, U1.10 (PA4); also elsewhere on the board
PA5: R30.2, U1.11 (PA5); also elsewhere on the board
PA6: R29.2, U1.12 (PA6); also elsewhere on the board
PA7: R28.2, U1.13 (PA7); also elsewhere on the board
PA8: R27.2, U1.18 (PA8); also elsewhere on the board
PB1: Q7.3 (D); also elsewhere on the board
PB3: Q6.3 (D); also elsewhere on the board
PB4: Q5.3 (D); also elsewhere on the board
PB5: Q4.3 (D); also elsewhere on the board
PB6: Q3.3 (D); also elsewhere on the board
PB7: Q2.3 (D); also elsewhere on the board
Power meter: TP6.1 (1_1), U1.6 (PA0); also elsewhere on the board
SWCLK: U1.24 (PA14); also elsewhere on the board
SWDIO: U1.23 (PA13); also elsewhere on the board
Temperature: U1.8 (PA2); also elsewhere on the board
USB_D+: J1.3 (D+), U1.22 (PA12)
USB_D-: J1.2 (D-), U1.21 (PA11)
USB_sense: C21.2, R12.2, R13.1, U1.7 (PA1)
VDD1: C12.2, C13.2, C14.1, C15.2, C16.2, C22.2, R14.2, SW2.1, U1.1 (VDD), U1.5 (VDDA), U1.17 (VDD); also elsewhere on the board

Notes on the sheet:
SWD prog pins
Open drain IOs
Boot push buttons
Decoupling

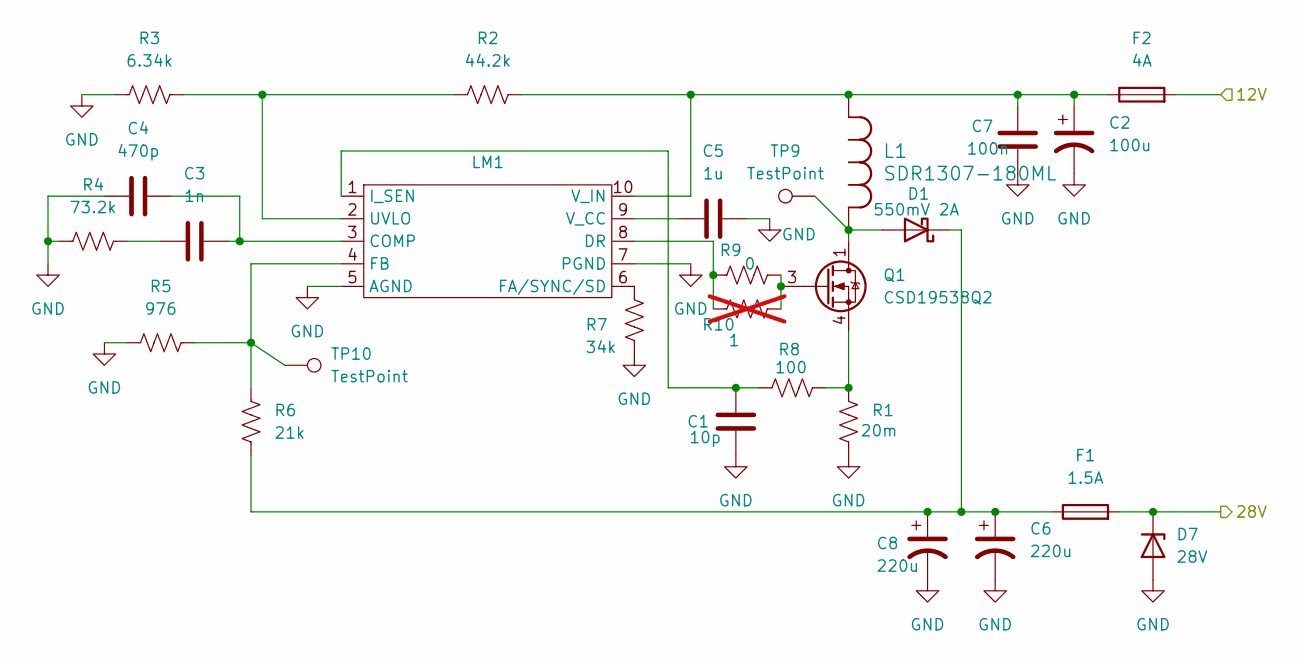
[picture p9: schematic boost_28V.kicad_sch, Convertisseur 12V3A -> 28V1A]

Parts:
C1: 10p; C_0603_1608Metric_Pad1.08x0.95mm_HandSolder
C2: 100u; CP_Elec_6.3x5.8
C3: 1n; C_0603_1608Metric_Pad1.08x0.95mm_HandSolder
C4: 470p; C_0603_1608Metric_Pad1.08x0.95mm_HandSolder
C5: 1u; C_0603_1608Metric_Pad1.08x0.95mm_HandSolder
C6, C8: 220u; CP_Elec_10x10
C7: 100n; C_0603_1608Metric_Pad1.08x0.95mm_HandSolder
D1: 550mV 2A; D_SOD-123F
D7: 28V; D_SMA_Handsoldering
F1: 1.5A; Fuse_1206_3216Metric_Pad1.42x1.75mm_HandSolder
F2: 4A; Fuse_1206_3216Metric_Pad1.42x1.75mm_HandSolder
L1: SDR1307-180ML; IND_BOURNS_SDR1307
LM1: TSSOP-10_3x3mm_P0.5mm
Q1: CSD19538Q2; Texas_DQK
R1: 20m; R_1206_3216Metric_Pad1.30x1.75mm_HandSolder
R2: 44.2k; R_0603_1608Metric_Pad0.98x0.95mm_HandSolder
R3: 6.34k; R_0603_1608Metric_Pad0.98x0.95mm_HandSolder
R4: 73.2k; R_0603_1608Metric_Pad0.98x0.95mm_HandSolder
R5: 976; R_0603_1608Metric_Pad0.98x0.95mm_HandSolder
R6: 21k; R_0603_1608Metric_Pad0.98x0.95mm_HandSolder
R7: 34k; R_0603_1608Metric_Pad0.98x0.95mm_HandSolder
R8: 100; R_0603_1608Metric_Pad0.98x0.95mm_HandSolder
R9: 0; SolderJumper-2_P1.3mm_Open_TrianglePad1.0x1.5mm
R10: 1; R_0603_1608Metric_Pad0.98x0.95mm_HandSolder; not fitted
TP9, TP10: TestPoint; TestPoint_Pad_D1.5mm

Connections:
+12V: F2.2; also elsewhere on the board
+28V: D7.1 (K), F1.2; also elsewhere on the board
GND: C1.2, C2.2, C4.1, C5.2, C6.2, C7.1, C8.2, D7.2 (A), LM1.5 (AGND), LM1.7 (PGND), R1.2, R3.2, R4.2, R5.2, R7.2; also elsewhere on the board
unnamed: C3.1, R4.1
unnamed: D1.2 (A), L1.1, Q1.1 (D), Q1.2 (D), Q1.5 (D), Q1.6 (D), Q1.8 (D), TP9.1 (1_1)
unnamed: C6.1, C8.1, D1.1 (K), F1.1, R6.2
unnamed: C3.2, C4.2, LM1.3 (COMP)
unnamed: LM1.8 (DR), R9.1, R10.1
unnamed: LM1.6 (FA/SYNC/SD), R7.1
unnamed: LM1.4 (FB), R5.1, R6.1, TP10.1 (1_1)
unnamed: C1.1, LM1.1 (I_SEN), R8.1
unnamed: LM1.2 (UVLO), R2.1, R3.1
unnamed: C5.1, LM1.9 (V_CC)
unnamed: C2.1, C7.2, F2.1, L1.2, LM1.10 (V_IN), R2.2
unnamed: Q1.3 (G), R9.2, R10.2
unnamed: Q1.4 (S), Q1.7 (S), R1.1, R8.2

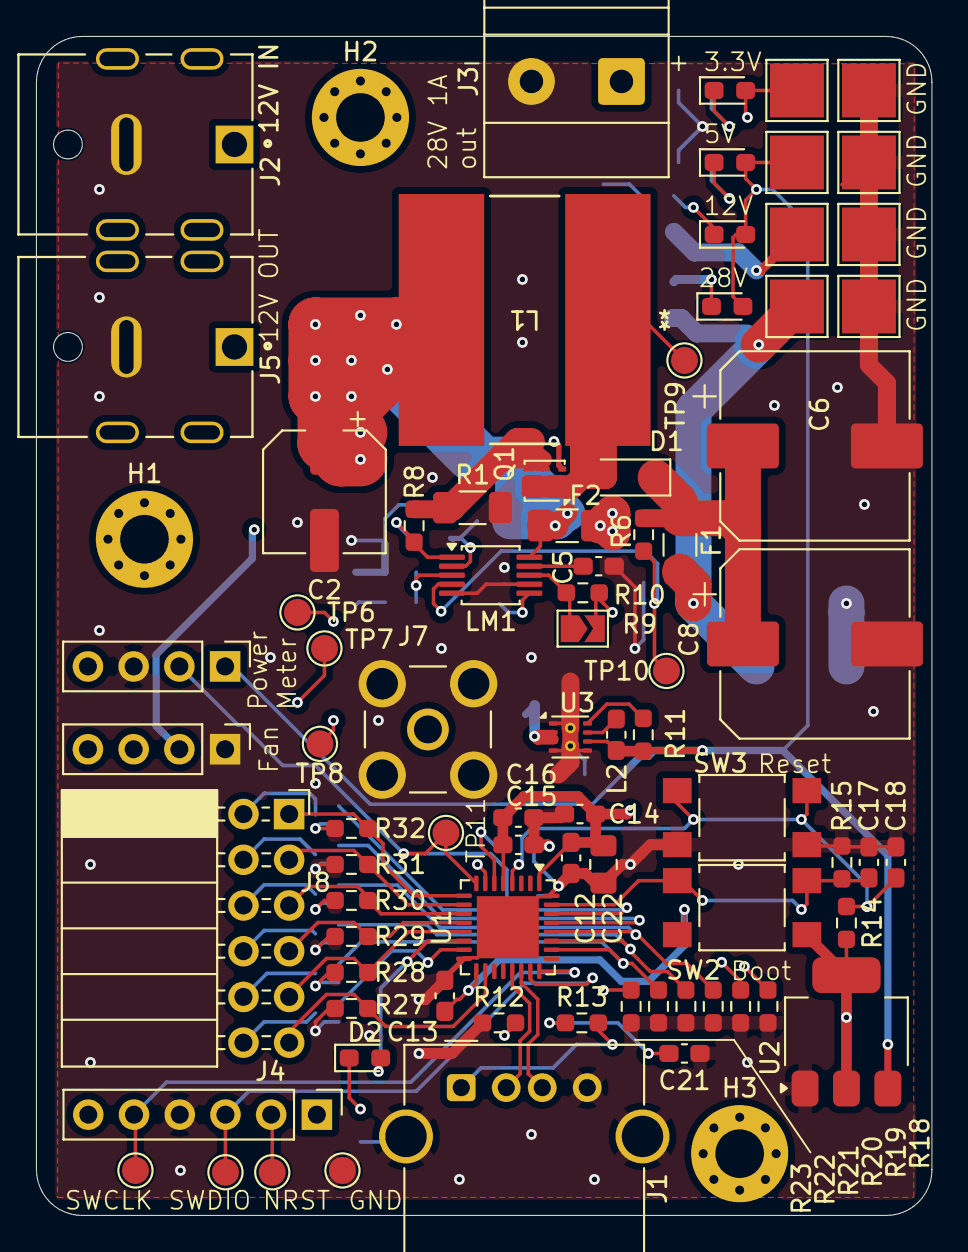
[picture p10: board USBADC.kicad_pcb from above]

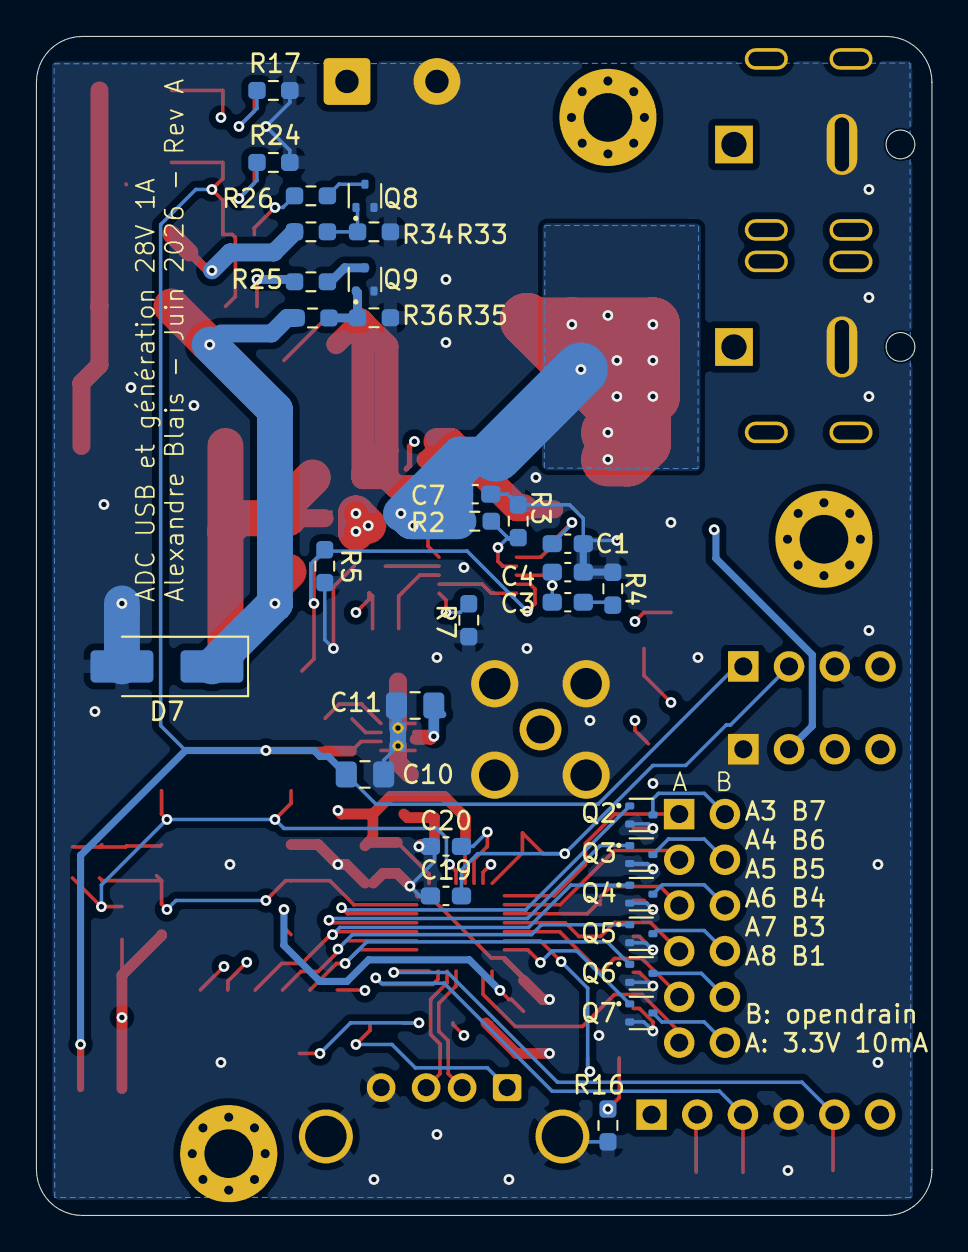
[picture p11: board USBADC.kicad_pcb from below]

Board: 4 copper layers, 49.8 x 65.5 mm, 113 parts (31 on the bottom side), 58 nets.

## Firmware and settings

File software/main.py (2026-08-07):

import time

from usbadc.USBADC import USBADC
from usbadc.packets import ADCChannel


usbadc = USBADC()
usbadc.ping()
usbadc.write_pin("GPIOB", 0, False)

while True:
    power_meter = usbadc.read_adc(ADCChannel.POWER_METER)
    usb_sense = usbadc.read_adc(ADCChannel.USB_SENSE)
    temperature = usbadc.read_adc(ADCChannel.TEMPERATURE)
    pin_a3 = usbadc.read_adc(ADCChannel.PIN_A3)

    print(f"Power meter: {power_meter}V")
    print(f"USB Sense: {usb_sense}V")
    print(f"Temperature: {temperature}V")
    print(f"Pin A3: {pin_a3}V")
    print()

    # time.sleep(1)

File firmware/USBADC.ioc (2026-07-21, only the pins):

Mcu.UserName=STM32U073K8Ux
PA0-CK_IN.Signal=ADC1_IN4
PA1.Signal=ADC1_IN5
PA2.Signal=ADC1_IN6
PA3.Signal=ADC1_IN7
PA4.Signal=S_LPTIM2_CH1
PA5.Signal=GPIO_Output
PA6.Signal=GPIO_Output
PA7.Signal=GPIO_Output
PA8.Signal=GPIO_Output
PB0.Signal=GPIO_Output
PB1.Signal=GPIO_Output
PB3.Signal=GPIO_Output
PB4.Signal=GPIO_Output
PB5.Signal=GPIO_Output
PB6.Signal=GPIO_Output
PB7.Signal=GPIO_Output

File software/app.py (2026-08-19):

from flask import Flask, render_template, jsonify, Response
import time
import threading
from bisect import bisect_right
from typing import List, Tuple

from usbadc.USBADC import USBADC
from usbadc.packets import ADCChannel

app = Flask(__name__)

usbadc = None
connect_lock = threading.Lock()


def interpolate(xy_values: List[Tuple[float, float]], value: float) -> float:
    if not xy_values:
        raise ValueError("xy_values cannot be empty")

    if len(xy_values) == 1:
        return xy_values[0][1]

    xs = [x for x, _ in xy_values]
    i = bisect_right(xs, value)

    if i == 0:
        return xy_values[0][1]
    if i == len(xy_values):
        return xy_values[-1][1]

    x0, y0 = xy_values[i - 1]
    x1, y1 = xy_values[i]

    return y0 + (value - x0) * (y1 - y0) / (x1 - x0)


def disconnect_usbadc():
    global usbadc

    old = usbadc
    usbadc = None

    if old is not None:
        try:
            old.disconnect()
        except Exception as e:
            print(f"Error closing USBADC: {e}")


def try_connecting_usbadc():
    global usbadc

    with connect_lock:
        if usbadc is not None:
            return True

        try:
            print("Trying to connect USBADC...")
            device = USBADC()
            usbadc = device
            print("USBADC connected")

            return True

        except Exception as e:
            print(f"USBADC connection failed: {type(e).__name__}: {e}")
            usbadc = None
            return False


def read_adc(channel):
    global usbadc

    # Connect if necessary
    if not try_connecting_usbadc():
        raise ConnectionError("USBADC not connected")

    try:
        return usbadc.read_adc(channel)

    except Exception as e:
        print(
            f"USBADC communication failed: "
            f"{type(e).__name__}: {e}"
        )

        # The existing USB connection is no longer usable.
        disconnect_usbadc()

        # Try creating a completely new USBADC object.
        if try_connecting_usbadc():
            try:
                return usbadc.read_adc(channel)
            except Exception as e2:
                print(
                    f"USBADC retry failed: "
                    f"{type(e2).__name__}: {e2}"
                )
                disconnect_usbadc()

        raise ConnectionError("USBADC communication failed")


@app.route("/")
def index():
    return render_template("index.html")


@app.route("/data/power_meter")
def data_power_meter():
    try:
        value = read_adc(ADCChannel.POWER_METER)
        value = interpolate([
            (0.50,  20),
            (0.60,  15),
            (0.73,  10),
            (0.97,  5),
            (1.00,  0),
            (1.11, -5),
            (1.21, -10),
            (1.36, -15),
            (1.48, -20),
            (1.60, -25),
            (1.71, -30),
            (1.87, -35),
            (2.00, -40),
            (2.05, -45),
            (2.1,  -50),
        ], value)

        return jsonify({
            "timestamp": time.time(),
            "value": value,
        })

    except ConnectionError:
        return Response("No USBADC detected", status=503)

    except TimeoutError:
        return Response("USBADC timed out", status=504)

    except Exception as e:
        print(f"Power meter error: {type(e).__name__}: {e}")
        return Response("USBADC error", status=500)


@app.route("/data/temperature")
def data_temperature():
    try:
        value = read_adc(ADCChannel.TEMPERATURE)
        # Depuis la datasheet:
        # v =  0.55 + (0.045 / 20)t
        # t = (v - 0.55) / (0.045 / 20)
        print(value)
        value = (value - 0.55) / (0.045 / 20) 
        print(value)

        return jsonify({
            "timestamp": time.time(),
            "value": value,
        })

    except ConnectionError:
        return Response("No USBADC detected", status=503)

    except TimeoutError:
        return Response("USBADC timed out", status=504)

    except Exception as e:
        print(f"Temperature error: {type(e).__name__}: {e}")
        return Response("USBADC error", status=500)


@app.route("/data/pin_a3")
def data_pin_a3():
    try:
        value = read_adc(ADCChannel.PIN_A3)

        return jsonify({
            "timestamp": time.time(),
            "value": value,
        })

    except ConnectionError:
        return Response("No USBADC detected", status=503)

    except TimeoutError:
        return Response("USBADC timed out", status=504)

    except Exception as e:
        print(f"PIN A3 error: {type(e).__name__}: {e}")
        return Response("USBADC error", status=500)


@app.route("/set_pin/<pin_str>/<state_str>")
def set_pin(pin_str: str, state_str: str):
    if (
        len(pin_str) <= 2
        or pin_str[0] != "P"
        or pin_str[1] not in "AB"
    ):
        return Response("Invalid pin", status=400)

    try:
        pin = int(pin_str[2:])
    except ValueError:
        return Response("Invalid pin", status=400)

    if not 0 <= pin < 16:
        return Response("Invalid pin", status=400)

    if state_str.lower() in ("true", "1", "on"):
        state = True
    elif state_str.lower() in ("false", "0", "off"):
        state = False
    else:
        return Response("Invalid state", status=400)

    if not try_connecting_usbadc():
        return Response("No USBADC detected", status=503)

    # TODO: perform the actual GPIO operation here.

    return jsonify({
        "timestamp": time.time(),
        "pin": pin_str,
        "state": state,
    })


if __name__ == "__main__":
    try_connecting_usbadc()

    app.run(
        host="0.0.0.0",
        port=5000,
    )

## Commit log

2026-07-16 Reading powermeter, USB sense and temperature and sending it over USB
2026-07-17 Fixed reading from CDC tested with a temporary echo loop tested with a temporary echo loop
    [USBADC.ioc, app_usbx_device.c, ux_device_cdc_acm.c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]
2026-07-17 Made it so replugging the device reboots it
    [app_usbx_device.c, ux_device_cdc_acm.c]
2026-07-17 Calibrate ADC
2026-07-20 Added 25KHz PWM output, untested The GPIO output is controlled via interrupts because it doesn't seem LPTIM2 supports PWM generation output on the STM32U073
    [USBADC.ioc, app_usbx_device.c, ux_device_cdc_acm.c]
2026-07-21 Fixed writing to USB from multiple places Added a ThreadX queue
    [USBADC.ioc, app_usbx_device.c, ux_device_cdc_acm.c]
2026-07-21 Added fan PWM generation
2026-07-21 Added conversion from ADC value to voltage
2026-07-27 Sampling thread now returns ADC values in millivolts Also fixed a buffer overflow in the sprintf usage
    [ux_device_cdc_acm.c]
2026-07-31 Fixed infinite loop and CRC32 implementation from CRC32-MPEG2 to CRC32 I also sprinkled some log statements for debugging, I'm not able to make use of GDB efficiently I also fixed an unaligned read, 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
    [protocol.h, ux_device_cdc_acm.c]
2026-08-03 Implemented reading the ADC from USB
2026-08-03 Fixed ADC_READ returning data in native endianness
    [ux_device_cdc_acm.c]
2026-08-03 Declared shared variables volatile I want to avoid the compiler doing funny stuff with them.
    [ux_device_cdc_acm.c]
2026-08-04 Added hardware subfolder with KiCad 10.0.0 schematics
    [MCU.kicad_sch, USBADC.csv, USBADC.kicad_pcb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]
2026-08-04 Ajout image pour identifier les parties du PCB
2026-08-04 Ajout des versions des logiciels utilisés
2026-08-04 Added a reader thread into the Python lib
2026-08-05 Fixed race condition when writing to pyserial's Serial stream
    [USBADC.py, main.py]
2026-08-05 Replaced ChecksumDiffers error to ValueError
    [USBADC.py, main.py]
2026-08-06 Fixed decoding length could be too big
    [USBADC.py, packets.py]
2026-08-07 Removed logging feature as it caused problems with communication
    [main.py, packets.py, protocol.h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]
2026-08-07 Fix device detection on Windows
    [USBADC.py]
2026-08-12 Fix compilation avec STM32CubeIDE
    [ux_device_cdc_acm.c]
2026-08-17 Renommer PB2 -> PB1 parce que mauvaise pin
2026-08-17 Reconnection automatique de l'USBADC pour le serveur web
2026-08-19 Clarifications pour la programmation
2026-08-19 Ajout de traduction de tension à puissance et température
2026-08-20 Ajout des librairies nécessaires
